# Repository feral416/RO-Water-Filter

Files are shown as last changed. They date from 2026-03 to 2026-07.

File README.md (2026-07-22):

# Reverse Osmosis Water Filter Controller

## Intro

Project designed to automate home electric RO water filter system that includes intake shutoff valve, pump and optionally automatic flush valve, using microcontroller Arduino Pro Micro(ATmega32U4). Project has low cost, requires minimum components and uses no extra sensors and actuators.

**Aims of the project:**

- Make operation safer.
- Prolong lifespan of valves and pump by eliminating major flaws of pure electric control.
- Prevent extra wear of filters.
- Make diagnostics easier.
- Make it possible to work from unpressurized water source without rewiring.

Basic electric circuit has two sensors for low and high pressure, if pressure is not high and not low respective contacts are closed and power supplied to the actuators: intake shutoff valve, diaphragm pump and automatic flush valve that bypasses drain restriction for short period of time. The major flaw is that low pressure sensor doesn't have deadband at certain low pressure, when sensor is not tripped, starting the pump causes pressure drop and sensor trips which turns off actuators and pressure becomes sufficient again and cycle continues. This self-oscillating process has period less than a second causing major wear to valves and pump mechanics, electrical parts work at inrush current producing excessive heat which in turns can damage the insulation of windings. Second problem is frequent turn on and off caused by opening a tap for a short period of time so closing it will cause pressure to trip high pressure sensor again thus de-energizing the actuators. Third problem is there is no protection from sensors or pump malfunction and accidental leaving the tap open.

## Hardware

Electric schematics made with KiCad, hydraulics diagram made with FluidSIM, PDF versions are available in respective folder.

The main controller is Arduino Pro Micro(ATmega32U4) reads 3 signals from two sensors and a switch, output 3 signals to 2 LEDs and one to actuators, that controlled with logic-level MOSFET. MC is powered from 24V main supply using L7805 linear voltage regulator. User panel consist of: two LEDs- yellow and red, a switch. Diodes are used to protect from kickback voltages. Cap C3 filtering ripple from DC motor operation.

Note that high pressure sensor breaks the circuit so as detected by the MC. It's made intentionally redundant to protect from dangerous pressure to build-up or continuous uncontrolled operation due to controller or MOSFET fault.

Power consumption of the device is 14mA(max) at 24V- 0.336W, 40mA during boot.

## Software

Software is written in PlatformIO with C++ using Arduino framework. Software is compatible with any other Arduino-compatible board.

**Software functions:**

- Monitors state of sensors.
- Prevent operation in undesired conditions: low pressure or too high pressure.
- Prevent indefinite operation due to inability to build up pressure by limiting continuous operation time.
- Prevent frequent turning on/offs caused by low water pressure by adding progressive delay between retries: 10-30-60 minutes
   thus making it self-recoverable condition.
- Prevent frequent operation by requiring high-pressure sensor to stay closed for 30s and making 10m delay between turn-ons.
- Display sensors state and faults.
- Allowing to bypass low pressure sensor, reset the faulty state, bypass waiting between switching on.

Loading program only possible shortly(~12s) after reboot.

In order to save power in program is used power down mode, which uses inaccurate wdt timer with tolerance +-20%, so all time operations will be inaccurate, due to that interval time has to be calibrated to exact used devise. In this project interval increased by 18.3% from default 60 to 71ms. Anyways for that project such time drift isn't critical.

Software has a watchdog to prevent mc to hang during program execution leaving outputs in high state, if program won't respond in 3s mc watchdog will reboot the mc.

## Operation manual

Normal operation doesn't require any user interaction with the controller.

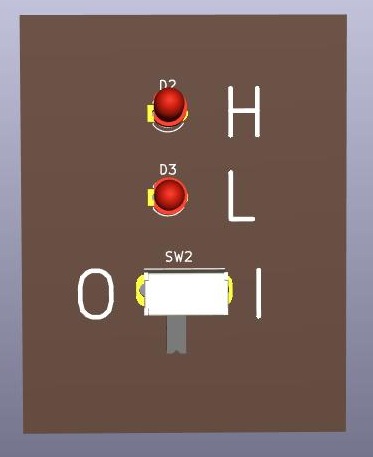
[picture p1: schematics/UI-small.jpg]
Front panel


**Front panel**

Front panel yellow LED(H) displays state of high pressure sensor, if continuos on means high pressure is reached or sensor's wire is broken. If the LED flash it signals that maximum operation time is reached(1h), that can be reset by switching switch on-off or turning off/on the power supply.

Front panel red LED(L) displays the state of low pressure sensor, if continuous on means that pressure is low or sensor wire is broken. If the LED flash that means low pressure turned on rapidly and gone quickly, which is faulty state and the controller waits some time to try turn on actuators again. This fault recovers by itself or switching the switch on/off or turning off/on the power supply.

Front panel switch resets faults and turn on the maintenance mode that allows operation without delays and ignores low pressure sensor.

If none of LEDs is on means that program is either waiting in restart delay or actuators work.

Built-in arduino green LED signals that power is on.

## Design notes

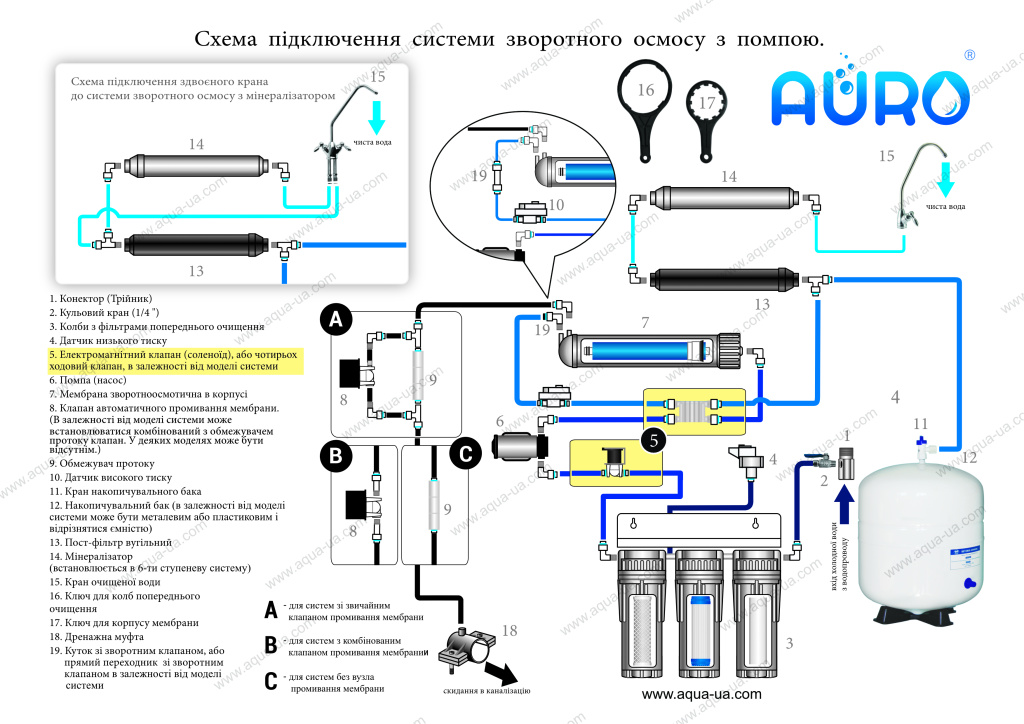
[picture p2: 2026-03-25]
schematics/filter schematics.jpg

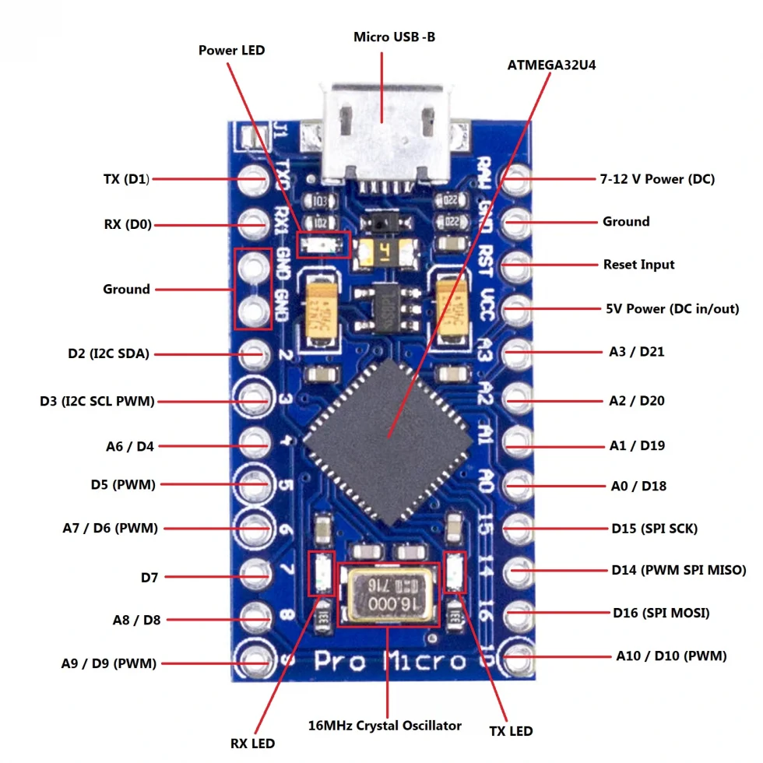
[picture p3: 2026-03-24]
datasheets/Arduino-Pro-Micro-Pinout-Diagram-Gadget-AU-980x980.webp

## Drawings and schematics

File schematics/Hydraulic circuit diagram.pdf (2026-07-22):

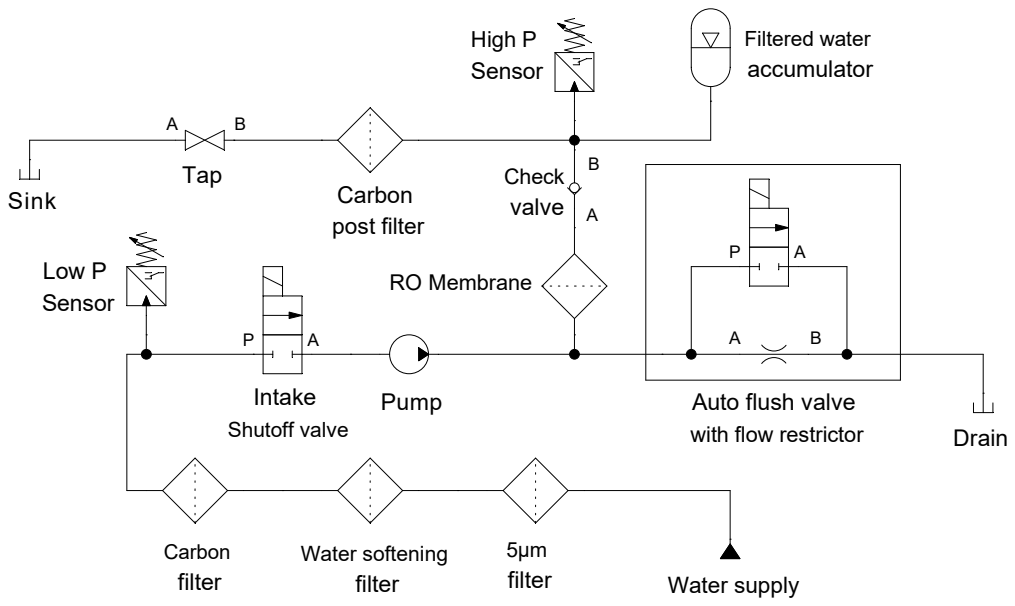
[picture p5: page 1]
5µm filter; Water softening filter; Carbon filter; Intake; Pump; Shutoff valve; Low P Sensor; Tap; Carbon post filter; RO Membrane; Water supply; Drain; Sink; High P Sensor; Filtered water accumulator; Check valve

Auto flush valve
with flow restrictor

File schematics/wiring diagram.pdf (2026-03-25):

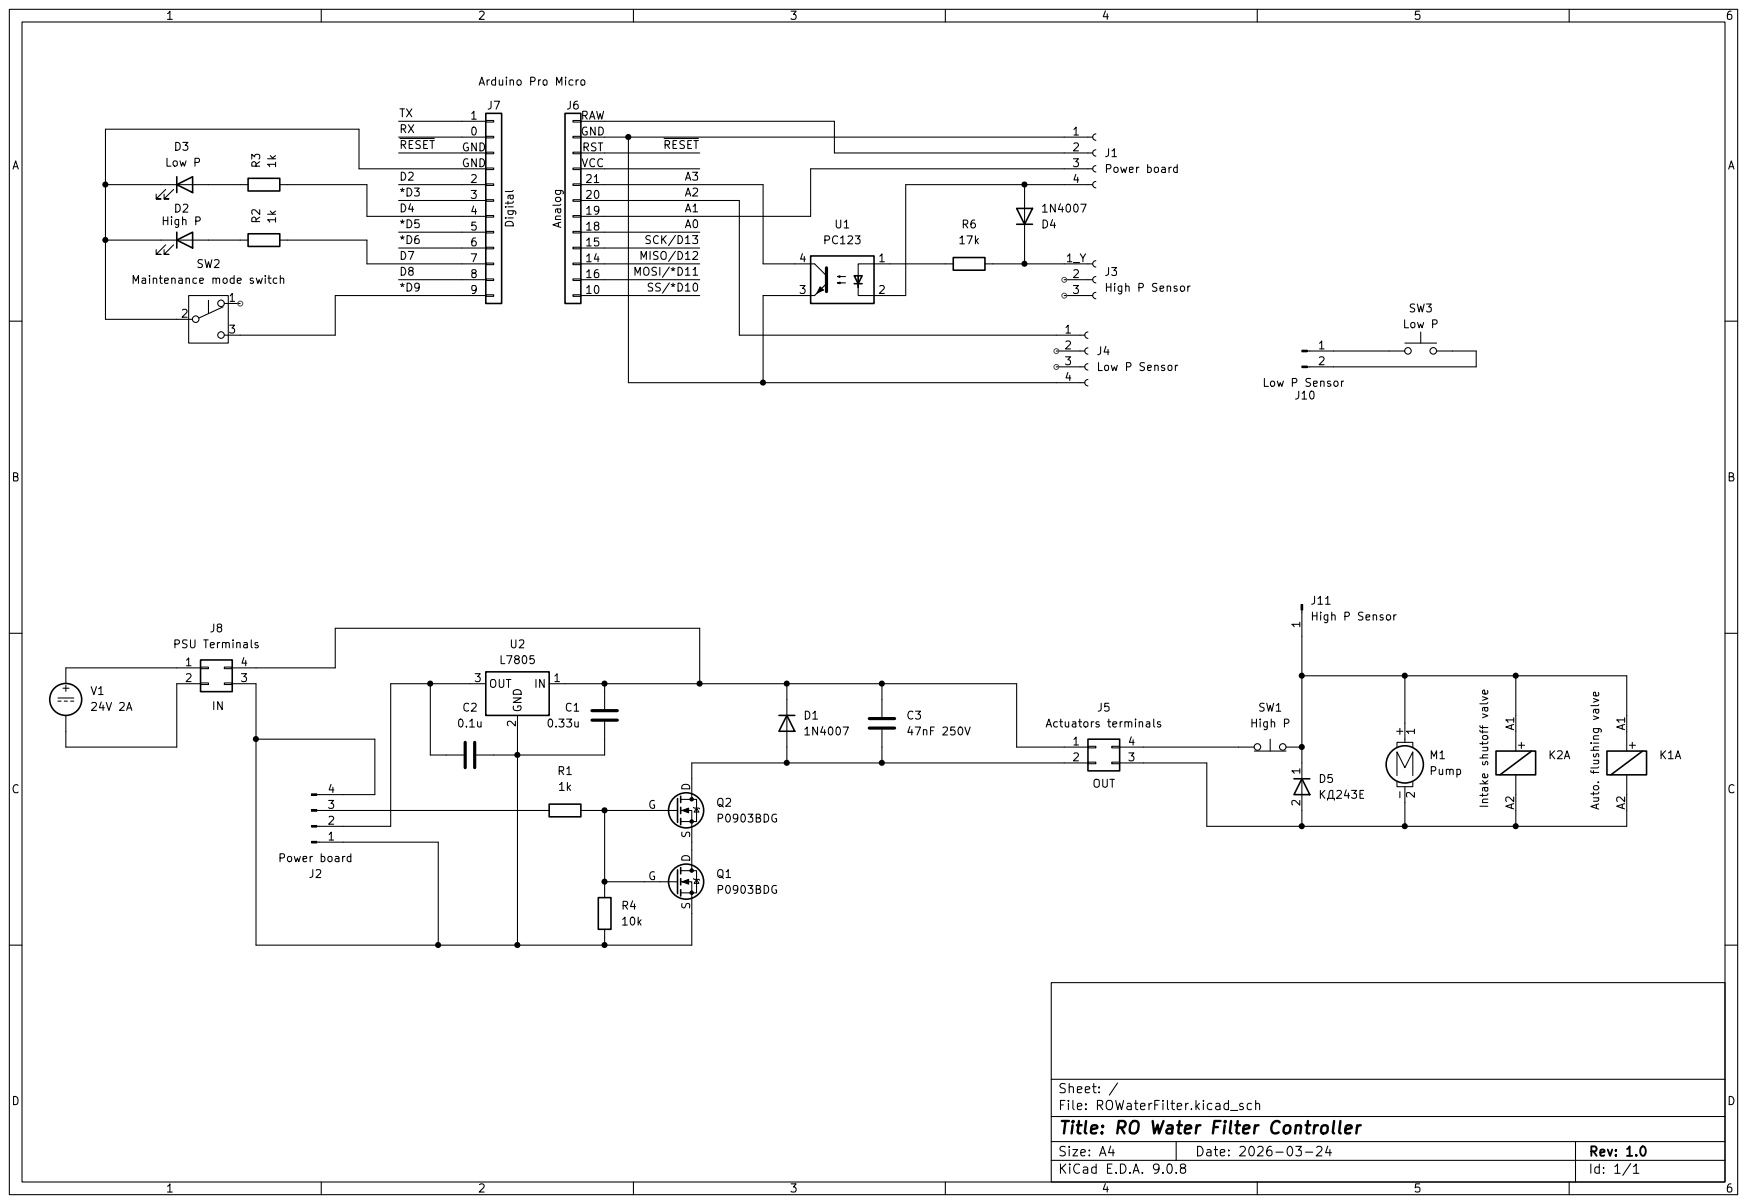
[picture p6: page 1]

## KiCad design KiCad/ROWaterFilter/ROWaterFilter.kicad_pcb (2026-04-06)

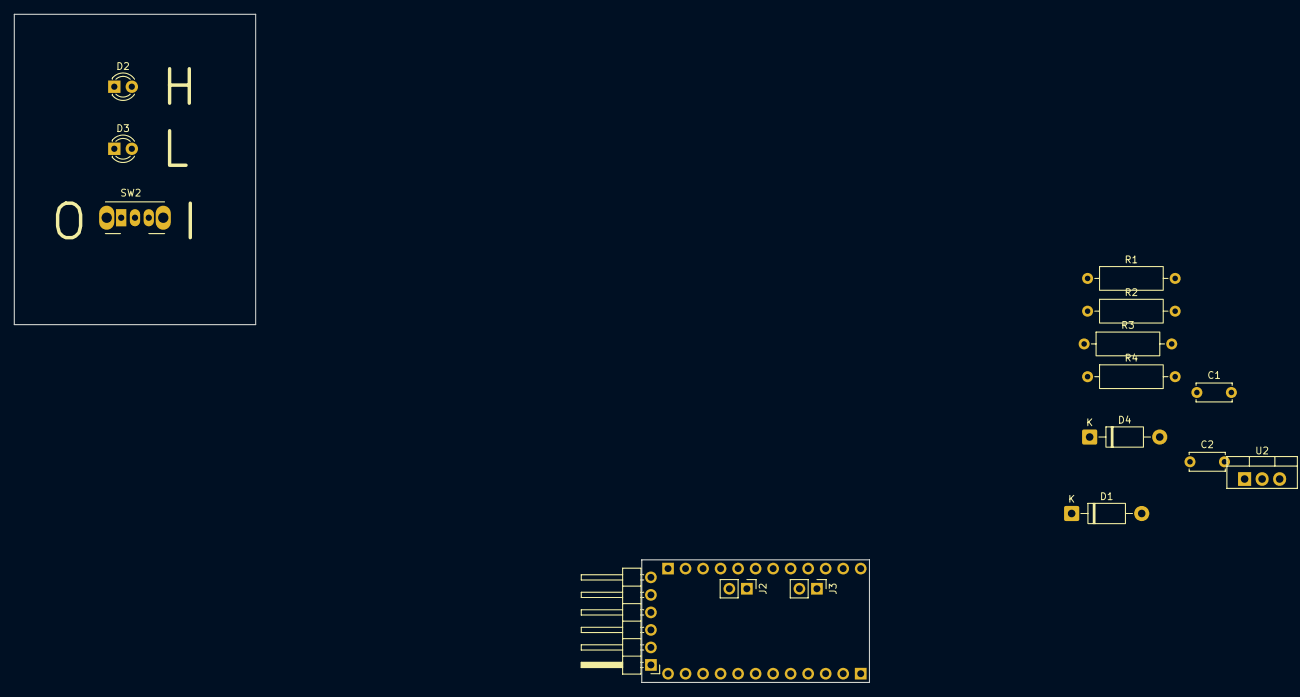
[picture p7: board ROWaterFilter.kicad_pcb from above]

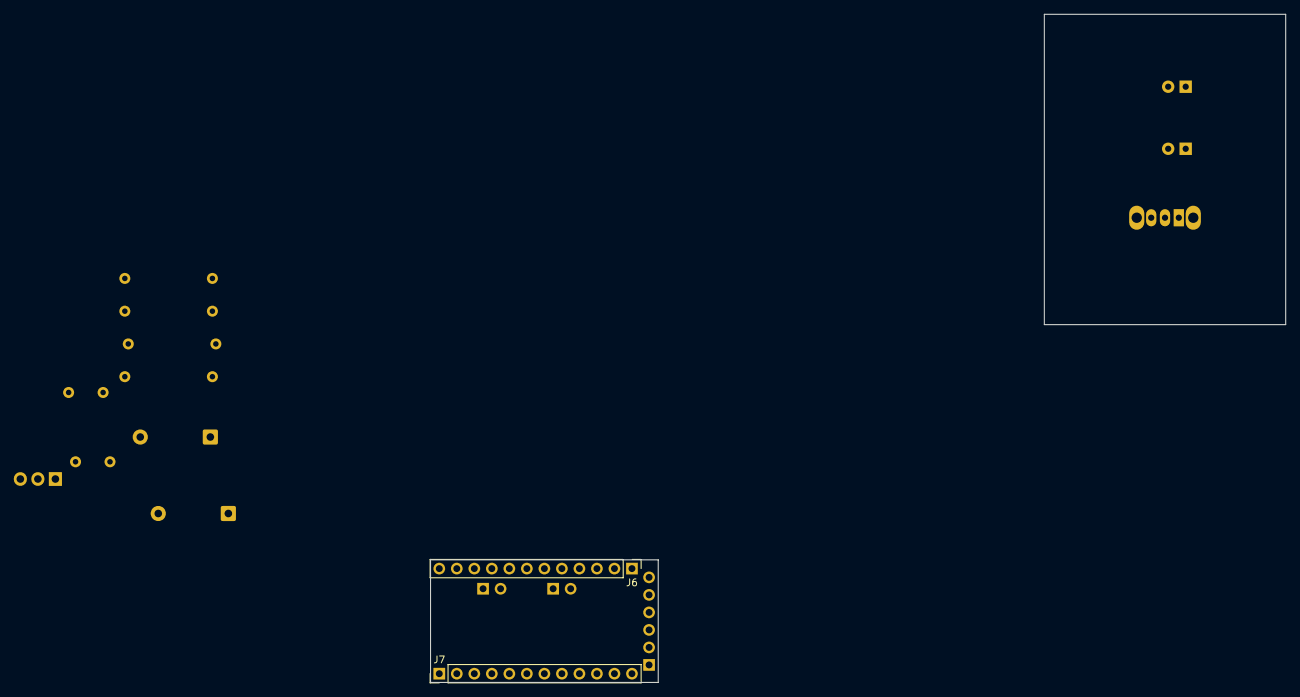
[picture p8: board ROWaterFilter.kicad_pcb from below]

Board: 2 copper layers, 17 parts (2 on the bottom side), 12 nets, no tracks yet.

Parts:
C1: 0.33u; C_Disc_D5.0mm_W2.5mm_P5.00mm
C2: 0.1u; C_Disc_D5.0mm_W2.5mm_P5.00mm
D1, D4: 1N4007; D_DO-41_SOD81_P10.16mm_Horizontal
D2: High P; LED_D3.0mm
D3: Low P; LED_D3.0mm
J1: FTDI; PinHeader_1x06_P2.54mm_Horizontal
J2: I2C; PinHeader_1x02_P2.54mm_Vertical
J3: Analog; PinHeader_1x02_P2.54mm_Vertical
J6: Analog; PinHeader_1x12_P2.54mm_Vertical
J7: Digital; PinHeader_1x12_P2.54mm_Vertical
R1, R2, R3: 1k; R_Axial_DIN0309_L9.0mm_D3.2mm_P12.70mm_Horizontal
R4: 10k; R_Axial_DIN0309_L9.0mm_D3.2mm_P12.70mm_Horizontal
SW2: Maintenance mode switch; SW_Slide_SPDT_Angled_CK_OS102011MA1Q
U2: L7805; TO-220-3_Vertical

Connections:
/*D9: J7.9 (Pin_1), SW2.3 (C)
/D4: J7.4 (Pin_6), R3.2
/D7: J7.7 (Pin_3), R2.2
/TX: J1.5, J7.1 (Pin_12)
GND: J1.1, J1.2
unnamed: C1.1, D1.1 (K), U2.1 (IN)
unnamed: D2.2 (A), R2.1
unnamed: D2.1 (K), D3.1 (K), SW2.2 (B)
unnamed: D3.2 (A), R3.1
unnamed: C1.2, C2.1, R4.2, U2.2 (GND)
unnamed: C2.2, U2.3 (OUT)
unnamed: R1.1, R4.1

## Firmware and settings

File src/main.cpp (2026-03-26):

#include <Arduino.h>
#include "../lib/utils/src/utils.hpp"
#include "LowPower.h"
#include "avr/wdt.h"

constexpr uint32_t SECOND = 1000; // 1k ms in second
constexpr uint32_t MINUTE = 60000; // 60k milliseconds
constexpr uint8_t watchdog_time = WDTO_2S;
// interval calibrated on real mc cuz default is inaccurate
constexpr uint32_t execution_interval = 71; // ms
constexpr uint8_t LOW_PRESSURE_PIN = 20;
constexpr uint8_t HIGH_PRESSURE_PIN = 21;
constexpr uint8_t MAINTENANCE_SWITCH_PIN = 9;
constexpr uint8_t PUMP_SOLENOID_CTRL_PIN = 19;
constexpr uint8_t LOW_PRESSURE_DIODE_PIN = 4;
constexpr uint8_t HIGH_PRESSURE_DIODE_PIN = 7;

class App {
  public:
    // progressive auto restart delays in minutes
    enum Waiting_time {
      NONE = 0,
      NORMAL = 5, 
      PROLONGED = 30, //30
      LONG = 60
    };

    uint32_t system_time = 0;
    DI low_pressure = DI(LOW_PRESSURE_PIN, SECOND / 2 , SECOND / 2, false);
    DI high_pressure = DI(HIGH_PRESSURE_PIN, SECOND / 2, SECOND / 2, false);
    DI maintenance_switch = DI(MAINTENANCE_SWITCH_PIN, SECOND / 2, SECOND / 2, true); // 500 ms
    DO pump_solenoid_ctrl = DO(PUMP_SOLENOID_CTRL_PIN, 2 * SECOND, 2 * SECOND);
    DO low_pressure_diode = DO(LOW_PRESSURE_DIODE_PIN, 0, 0);
    DO high_pressure_diode = DO(HIGH_PRESSURE_DIODE_PIN, 0, 0);
    enum Waiting_time restart_delay_time = NORMAL;
    uint8_t low_pressure_fault_count = 0;
    TON restart_delay_timer;
    TON operation_timer = TON(60 * MINUTE); // max operation time
    uint8_t state = 0;
    bool pump_solenoid_out = LOW;
    bool yellow_diode = false;
    bool red_diode = false;
    Blinker blinker = Blinker(0.25 * SECOND);
    // noticeable pressure drop
    TON high_pressure_drop = TON(30 * SECOND);

    void setup() {
      pinMode(LOW_PRESSURE_PIN, INPUT_PULLUP);
      pinMode(HIGH_PRESSURE_PIN, INPUT_PULLUP);
      pinMode(MAINTENANCE_SWITCH_PIN, INPUT_PULLUP);
      pinMode(LOW_PRESSURE_DIODE_PIN, OUTPUT);
      pinMode(HIGH_PRESSURE_DIODE_PIN, OUTPUT);
      // setting main output pin to low to prevent high state
      digitalWrite(PUMP_SOLENOID_CTRL_PIN, LOW);
      pinMode(PUMP_SOLENOID_CTRL_PIN, OUTPUT);
      // turning off red rx/tx diodes that draw 500mW on ProMicro!
      pinMode(LED_BUILTIN_RX, INPUT);
      pinMode(LED_BUILTIN_TX, INPUT);
      // sleeping to be able to connect to USB w/o reset
      delay(5 * SECOND);
      // enabling watchdog timer
      wdt_enable(watchdog_time);
      // disabling usb to prevent usb reconnects due to powerdowns
      UDCON |= (1 << DETACH);
    }

    void loop() {
      // kick the dog
      wdt_reset();

      // saving starting time
      uint32_t start_time = millis();

      //reading inputs
      low_pressure.read(system_time);
      high_pressure.read(system_time);
      maintenance_switch.read(system_time);

      // updating blinker
      blinker.update(system_time);

      // yellow diode display high pressure sensor by default
      yellow_diode = high_pressure.val();
      // red diode display low pressure sensor by default
      red_diode = low_pressure.val();
      // Monitor high pressure noticeable drop to prevent frequent short switching on/off
      // due to actual pressure still enough to trip the high pressure switch.
      // Pressure has to stay low for "preset" time at least to start actuators
      // in normal mode.
      high_pressure_drop.Update(!high_pressure.val(), system_time);

      switch (state) {
        case 0:
        // idle
          restart_delay_timer.Reset();
          operation_timer.Reset();
          pump_solenoid_out = LOW;
          if ((maintenance_switch.val() && !high_pressure.val())
              || (!low_pressure.val() && high_pressure_drop.OUT())) {
            state = 10;
            break;
          }
          break;
        case 10:
        // operation
          pump_solenoid_out = HIGH;
          if (low_pressure.val() && !maintenance_switch.val()) {
            if (low_pressure_fault_count <= 2) {
              low_pressure_fault_count++;
            }
            state = 20;
            break;        
          }
          if (high_pressure.val()) {
            state = 20;
            low_pressure_fault_count = 0;
            break;
          }
          if (operation_timer.Update(true, system_time)) {
            state = 100;
          }
          break;
        case 20:
        // restart delay
          pump_solenoid_out = LOW;
          if (maintenance_switch.val()) {
            state = 0;
            low_pressure_fault_count = 0;
            break;
          }
          switch (low_pressure_fault_count) {
            case 0:
            case 1:
              restart_delay_time = NORMAL;
              break;
            case 2:
              restart_delay_time = PROLONGED;
              break;
            default: 
              restart_delay_time = LONG;
          }
          restart_delay_timer.Preset = restart_delay_time * MINUTE;
          if (restart_delay_timer.Update(true, system_time)) {
            state = 0;
            break;
          }
          if (low_pressure_fault_count > 1) {
            red_diode = blinker.val();
          }
          break;
        case 100:
        // fault: unable to build pressure in time
          pump_solenoid_out = LOW;
          yellow_diode = blinker.val();
          if (maintenance_switch.val()) {
            state = 0;
            break;
          }
          break;
        default: 
          state = 0;
      };
      // writing outputs
      pump_solenoid_ctrl.write(pump_solenoid_out, system_time);
      low_pressure_diode.write(red_diode, system_time);
      high_pressure_diode.write(yellow_diode, system_time);

      // disabling watchdog before powerdown to prevent unwanted resets
      wdt_disable();
      // powering down mc to save power
      LowPower.powerDown(SLEEP_60MS, ADC_OFF, BOD_ON);
      // reeanabling watchdog again
      wdt_enable(watchdog_time);
      // updating time
      system_time += execution_interval + (millis() - start_time);
    }
};

App app;

void setup() {
  app.setup();
}

void loop() {
  app.loop();
}

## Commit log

2026-03-25 add: manual, description to readme; comments in code
    [ROWaterFilter.kicad_sch]
2026-03-26 add: powerdown mode, freeze watchdog
2026-04-06 docs, refactor, feat: readme update, refactor timers in lib, add time calibration function
    [ROWaterFilter.kicad_pcb, ROWaterFilter.kicad_sch]
2026-04-06 docs: hydraulic schematic elements names correctected, minor readme edit
2026-07-22 docs: updated hydraulic schematics
